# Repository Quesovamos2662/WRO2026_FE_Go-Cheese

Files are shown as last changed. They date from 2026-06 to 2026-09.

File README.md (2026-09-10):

<h1 align="center">🧀 Welcome to the Go!Cheese Repository 🧀</h1>

<div align="center">

━━━━━━━━━━━━━━━━━━━━━━━━━━━━━━━━━━━━

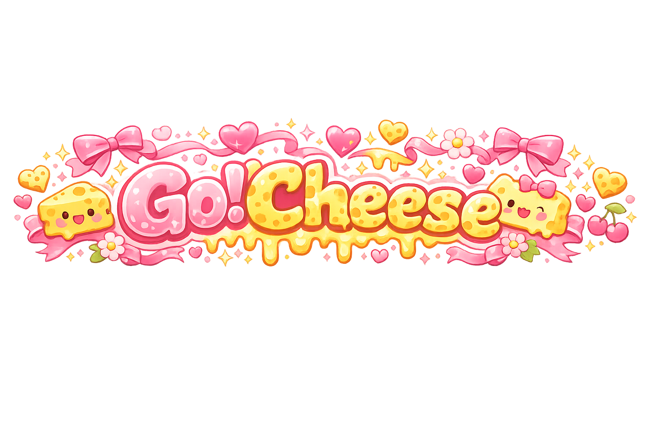
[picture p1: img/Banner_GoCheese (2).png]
Go!Cheese


━━━━━━━━━━━━━━━━━━━━━━━━━━━━━━━━━━━━

</div>

<h3 align="center"><em>"Cheese does run away from rats, right?"</em></h3>

<p align="center">
  
  
  
  
</p>

<p align="center">
  
  
  
  
  
</p>

---

Welcome to the official repository of **Go!Cheese**, a robotics team from San Miguelito, Panama, competing in the **WRO Future Engineers 2026** season.

This repository documents the complete engineering journey behind our autonomous vehicle, **Cheese**. It includes the development of the chassis, steering, drivetrain, electronics, sensors, vision system, software, testing process, failures, redesigns, and the decisions that eventually produced our current **Cheese v4**.

Our goal is not only to show the final robot.

We want the repository to explain:

> **What we built → why we built it that way → what failed → what we changed → what happened next.**

<div align="center">

| Project Information | Current Configuration |
| :--- | :--- |
| **Competition** | WRO Future Engineers 2026 |
| **Team** | Go!Cheese |
| **Region** | San Miguelito, Panama |
| **Current Robot** | Cheese v4 |
| **Controller** | LEGO Mindstorms EV3 |
| **Programming** | Python 3 (`ev3dev2`) + C++ Arduino bridge |
| **Vision** | HuskyLens |
| **Vision Interface** | Arduino Nano |
| **Propulsion** | EV3 Large Motor |
| **Steering** | EV3 Medium Motor + Ackermann geometry |
| **Distance Sensors** | 3 EV3 Ultrasonic Sensors |
| **Floor Detection** | EV3 Color Sensor |
| **Current Mass** | **666 g** |

</div>

---

<h3 align="center">Check us out! 👇</h3>

<p align="center">
  <a href="https://www.youtube.com/@GoCheese-pty" target="_blank">
    
  </a>
  <a href="https://github.com/Quesovamos2662" target="_blank">
    
  </a>
</p>

---

# WRO2026_FE_Go!Cheese

## 📌 Project Rundown

### Cheese Goal & Structure

Cheese is an autonomous LEGO Mindstorms EV3 vehicle designed for the **WRO Future Engineers 2026** competition.

The current robot is **Cheese v4**, the fourth major version of our platform.

Rather than using one fixed movement sequence, Cheese repeatedly reads its sensors and chooses a response based on the current situation.

Its main navigation systems include:

- PID wall-distance correction,
- progressive wall protection,
- color-based curve counting,
- front-distance safety,
- reverse recovery,
- obstacle recognition,
- camera-based steering influence,
- and final parking logic.

The software and mechanical architecture were designed together.

A good PID controller cannot compensate forever for a loose steering mechanism.

A correctly trained camera cannot help if the robot never places the obstacle inside its field of view.

A good color algorithm cannot work consistently if the sensor is mounted too far from the floor.

For this reason, our development philosophy became:

<p align="center">
  <strong>
    Mechanics + Sensors + Software + Testing = Reliable Behavior
  </strong>
</p>

---

### Open Challenge Logic

The Open Challenge is currently the most reliable part of Cheese v4.

The robot uses:

- left ultrasonic distance,
- right ultrasonic distance,
- front ultrasonic safety information,
- EV3 Color Sensor readings,
- PID steering,
- wall protection,
- curve validation,
- and parking logic.

A simplified Open control cycle is:

```text
START
  ↓
INITIALIZE
  ↓
READ ULTRASONIC SENSORS
  ↓
READ COLOR SENSOR
  ↓
CHECK FRONT SAFETY
  ↓
WALL PROTECTION?
  ↓
PID / STEERING CORRECTION
  ↓
VALID COLOR TRANSITION?
  ↓
UPDATE CURVE COUNT
  ↓
12 CURVES?
  ├── NO → CONTINUE
  └── YES → FINAL PARKING
```

A valid curve is based on a confirmed transition between the track colors:

```text
BLUE → ORANGE
```

or:

```text
ORANGE → BLUE
```

The current program expects:

```text
4 curves per lap × 3 laps = 12 curves
```

After the twelfth validated curve, Cheese enters its final parking procedure.

---

### Obstacle Challenge Logic

The Obstacle Challenge adds the **HuskyLens + Arduino Nano** vision subsystem.

The data path is:

```text
HuskyLens
    ↓
I2C
    ↓
Arduino Nano
    ↓
USB
    ↓
EV3
    ↓
Obstacle Navigation Logic
    ↓
Steering + Drive
```

The camera is currently trained for the competition obstacle colors:

| HuskyLens ID | Pillar | Required Passing Side |
| :---: | :---: | :--- |
| **ID 1** | 🔴 Red | Pass on the **right** |
| **ID 2** | 🟢 Green | Pass on the **left** |

The current obstacle challenge is functional but still being calibrated.

The main difficulty is no longer only recognizing the pillar.

It is completing the entire chain:

<p align="center">
  <strong>
    Detect → React → Avoid → Clear → Recover → Prepare for Next Obstacle
  </strong>
</p>

Post-obstacle recovery remains one of our main development priorities.

---

# General Project Index

This index connects the complete engineering documentation of Cheese.

Each section focuses on one part of the robot while remaining connected to the complete system.

---

## 🧀 General Project Overview

### [General Project Overview](sections/01-mobility-and-mechanical-design/project%20overview.md)

- Introduces Cheese and the WRO Future Engineers project.
- Explains the current Cheese v4 architecture.
- Summarizes the mechanical, electrical, software, sensing, testing, and development strategy.
- Introduces the progression from earlier versions to the current robot.

---

# 1. Mobility and Mechanical Design

## [1.1 Mechanical Design](sections/01-mobility-and-mechanical-design/1.1-mechanical-design.md)

- Explains the mechanical architecture behind Cheese.
- Documents propulsion and steering motor selection.
- Covers wheel decisions, drivetrain behavior, mechanical calculations, and testing.
- Connects mechanical changes to observed driving behavior.
- Documents changes introduced in Cheese v4.

## [1.2 Structural Components](sections/01-mobility-and-mechanical-design/1.2-structural-component.mds.md)

- Documents the LEGO Technic components used throughout the chassis.
- Explains liftarms, pins, axles, connectors, and critical supports.
- Separates critical structure from removable structure.
- Shows how v4 removed unnecessary components while keeping important mechanical supports.
- Includes structural evidence from the v3 → v4 redesign.

## [1.3 Steering and Drive](sections/01-mobility-and-mechanical-design/1.3-steering-and-drive.md)

- Explains the EV3 Large Motor rear-wheel-drive system.
- Explains the EV3 Medium Motor steering mechanism.
- Documents the Ackermann steering geometry.
- Shows how the steering linkage transfers motor rotation to the front wheels.
- Includes v1 → v2 → v3 → v4 steering development.
- Includes the dedicated v3 → v4 steering comparison.

## [1.4 Chassis Explanation](sections/01-mobility-and-mechanical-design/1.4-chassis-explanation.md)

- Explains how the chassis supports every major subsystem.
- Documents the lower EV3 position.
- Shows the motor, sensor, Nano, camera, and wiring placement.
- Explains the transition from the heavier v3 structure to the simplified v4 chassis.
- Documents the removal of unnecessary lighting and structural elements.

---

# 2. Power and Sensor Architecture

## [2.1 Power Supply and EV3](sections/02-power-and-sensor-architecture/2.1-power-supply-and-ev3.md)

- Documents the EV3 rechargeable battery.
- Explains the EV3 Brick as the central controller.
- Shows the lower physical EV3 placement in v4.
- Discusses battery consistency during testing.
- Explains why different battery conditions can affect physical motor response.
- Documents the use of two rechargeable EV3 batteries during repeated testing.

## [2.2 Wiring Diagram](sections/02-power-and-sensor-architecture/2.2-wiring-diagram.md)

- Documents the complete electrical architecture.
- Includes the system architecture diagram.
- Includes technical EV3 wiring.
- Explains sensor inputs and motor outputs.
- Documents the EV3 → Arduino Nano USB connection.
- Documents the Arduino Nano ↔ HuskyLens I2C connection.
- Includes real wiring photographs for reproducibility.

## [2.3 Sensor Selection and Placement](sections/02-power-and-sensor-architecture/2.3-sensor-selection-and-placement.md)

- Explains why Cheese uses three ultrasonic sensors.
- Documents left, right, and front ultrasonic placement.
- Explains the color sensor's floor-facing position.
- Documents the HuskyLens viewing position.
- Explains the compact front camera + ultrasonic arrangement.
- Connects physical sensor geometry to software reliability.

## [2.4 Sensor Calibration](sections/02-power-and-sensor-architecture/2.4-sensor-calibration.md)

- Documents color-sensor calibration.
- Explains the current EV3 color grouping.
- Covers ultrasonic filtering and distance thresholds.
- Documents PID calibration.
- Explains front-wall safety and reverse recovery.
- Documents HuskyLens obstacle IDs and camera reliability.
- Connects physical placement, sensor readings, and software interpretation.

---

# 3. Software and Obstacle Strategy

## [3.0 Cheese Logic Overview](sections/03-software-and-obstacle-strategy/3.0%20Cheese%20Logic%20Overview.md)

- Introduces the complete current software architecture.
- Explains the main sensor → decision → movement relationship.
- Separates Open Challenge logic from Obstacle Challenge logic.
- Introduces software priorities and safety behavior.

## [3.1 Algorithm Architecture](sections/03-software-and-obstacle-strategy/3.1-algorithm-architecture.md)

- Explains the internal software structure.
- Documents PID centering.
- Explains wall protection.
- Covers front-distance recovery.
- Documents color-based curve counting.
- Explains obstacle camera influence.
- Shows how competing behaviors are prioritized.

## [3.2 Flowchart](sections/03-software-and-obstacle-strategy/3.2-flowchart.md)

- Contains the current v4 software flowcharts.
- Shows the main software control cycle.
- Documents curve detection.
- Documents PID behavior.
- Shows front-wall reverse recovery.
- Shows obstacle camera behavior.
- Documents parking and sensor validation logic.

## [3.3 Open Challenge](sections/03-software-and-obstacle-strategy/3.3-open-challenge.md)

- Documents the current Open Challenge strategy.
- Explains wall following.
- Covers PID control and wall protection.
- Documents the front ultrasonic safety system.
- Explains curve counting.
- Covers the 12-curve / three-lap logic.
- Documents the current parking strategy.

## [3.4 Obstacle Challenge](sections/03-software-and-obstacle-strategy/3.4-obstacle-challenge.md)

- Explains red and green obstacle recognition.
- Documents HuskyLens communication through the Nano.
- Explains camera steering influence.
- Covers PID + camera interaction.
- Documents obstacle avoidance.
- Explains the current post-obstacle recovery problem.
- Records remaining testing priorities.

## [3.5 Corner Handling](sections/03-software-and-obstacle-strategy/3.5-corner-handling.md)

- Explains how Cheese enters and exits corners.
- Documents the BLUE ↔ ORANGE color sequence.
- Explains steering confirmation.
- Documents curve cooldown.
- Connects curve count directly to parking.
- Explains current corner failures and improvements.

## [3.6 Tuning Process](sections/03-software-and-obstacle-strategy/3.6-tuning-process.md)

- Documents the real tuning order used by the team.
- Covers mechanical tuning.
- Documents color calibration.
- Explains PID tuning.
- Covers curve tuning.
- Documents parking adjustments.
- Explains obstacle tuning.
- Records current Open and Obstacle status.

---

# 4. Engineering Decisions

## [4.1 Design Decision Log](sections/04-engineering-decisions/4.1-design-decision-log.md)

- Records major engineering decisions throughout development.
- Explains why components were added, moved, changed, or removed.
- Documents the transition from v3 to v4.
- Connects observed problems to engineering responses.
- Discusses trade-offs between mass, support, complexity, sensing, and reliability.

## [4.2 What Did Not Work](sections/04-engineering-decisions/4.2-what-didnt-work.md)

- Documents failures instead of hiding them.
- Explains mechanical failures.
- Covers sensor problems.
- Documents steering issues.
- Covers curve and parking failures.
- Explains unsuccessful lighting or structural strategies.
- Connects each failure to the next engineering decision.

---

# 5. Reproducibility

## [5.1 Bill of Materials](sections/05-reproducibility/5.1-bill-of-materials.md)

- Documents the components used in Cheese v4.
- Includes the EV3 Brick and rechargeable battery.
- Includes Large and Medium Motors.
- Includes the three ultrasonic sensors.
- Includes the EV3 Color Sensor.
- Includes the HuskyLens.
- Includes the Arduino Nano.
- Documents the LEGO Technic structural components.
- Separates critical and flexible components.

## [5.2 Build Instructions](sections/05-reproducibility/5.2-build-instructions.md)

- Provides a reproducible construction sequence.
- Documents chassis building.
- Explains motor installation.
- Covers Ackermann steering construction.
- Documents sensor mounting.
- Covers EV3 and Nano placement.
- References electrical wiring.
- Includes calibration and initial testing guidance.

---

# 6. Additional Resources

## [6.1 Additional Resources](sections/06-other-resources/6.1-additional-resources.md)

- Contains supporting engineering resources.
- Includes current v4 graphs.
- Includes historical v3 evidence where useful.
- Documents the transition between versions.
- Contains testing visualizations.
- Includes tuning and performance references.
- Supports deeper analysis beyond the main documentation.

---

# 7. Source Code

## [Source Code Folder](src/)

The `src/` folder contains the program files used during development.

The code history documents:

- Open Challenge development,
- Obstacle Challenge development,
- PID iterations,
- wall correction,
- curve counting,
- front recovery,
- camera integration,
- steering tests,
- parking logic,
- and experimental code versions.

Because software changed repeatedly during testing, older files are also useful engineering evidence.

They show how the current control system evolved rather than presenting the final program as if it appeared in one attempt.

---

# 8. Digital Models and Schemes

## [Robot Models](models/)

The models directory contains digital references related to Cheese's structure and development.

These resources complement physical photographs by helping document the robot's geometry and assembly.

## [Technical Schemes](schemes/)

The `schemes/` directory contains technical diagrams and reference documents.

Current resources include:

- complete system architecture,
- technical wiring,
- Nano ↔ HuskyLens wiring,
- final robot construction reference,
- steering comparison,
- and legacy wiring references.

<p align="center">
  <a href="schemes/Cheese_V4_Complete_System_Architecture_Wiring_Diagram.pdf">
    
  </a>
</p>

<p align="center">
  <a href="schemes/cheese_v4_technical_wiring_diagram.pdf">
    
  </a>
</p>

<p align="center">
  <a href="schemes/arduino_nano_huskylens_wiring_v4.pdf">
    
  </a>
</p>

<p align="center">
  <a href="schemes/steering_comparison_v3_to_v4.pdf">
    
  </a>
</p>

---

# 9. Visual Documentation

Our photo folders preserve the development of Cheese across the season.

## [Version 1 Photos](v-photos/v1/)

Documents the earliest physical ideas and provides historical evidence of the first steering and chassis concepts.

## [Version 2 Photos](v-photos/v2/)

Documents the first major physical competition version and important steering redesigns.

## [Version 3 Photos](v-photos/v3/)

Documents the heavier reinforced robot that preceded the current design.

Version 3 remains important because many v4 decisions were direct responses to problems identified in v3.

## [Version 4 Photos](v-photos/v4/)

Documents the **current Cheese v4** configuration.

The folder includes:

- front,
- back,
- left,
- right,
- top,
- bottom,
- chassis,
- motors,
- steering,
- ultrasonic sensors,
- color sensor,
- HuskyLens,
- Arduino Nano,
- battery,
- wiring,
- removed structural pieces,
- and removed lighting components.

---

# 10. Team Documentation

## [Team Photos](t-photos/)

The team documentation shows the people behind the vehicle and complements the technical engineering evidence.

---

<p align="center">
  <strong>
    This index connects every major part of the repository so the engineering process
    can be followed from concept → prototype → failure → redesign → testing → current v4.
  </strong>
</p>

---

<h2 align="center">🧀 Team Goals: Road to the National Finals 🧀</h2>

<p align="center">
  <em>
    Building Cheese is not only about competing. It is about learning how to think,
    test, fail, document, and improve like engineers.
  </em>
</p>

<div align="center">

| Goal | What We Want to Achieve |
| :--- | :--- |
| **🧊 Freeze Stable Code** | Once Open and Obstacle behavior reaches acceptable reliability, we want to avoid major last-minute changes and focus on repetition, calibration, and verification. |
| **🏁 Make Open Repeatable** | The current Open system can complete three laps and park. Our next objective is increasing repeatability across different starts and battery conditions. |
| **🚧 Complete Obstacle Reliability** | The HuskyLens can identify the pillars and affect movement, but avoidance and especially recovery still require calibration. |
| **📚 Make Documentation Count** | Every important decision should include the failure, cause, correction, result, and engineering lesson whenever evidence is available. |
| **🔧 Improve Reproducibility** | Another team should be able to understand Cheese's mechanics, sensors, wiring, software, and testing process from this repository. |
| **🏁 Earn Our Place at Nationals** | We want our performance and documentation to demonstrate how much Cheese improved throughout the season. |
| **🌱 Build a Reference for Future Us** | This is our first season in Future Engineers, so we want to leave behind a strong engineering foundation that can be improved later. |

</div>

<p align="center">
  <strong>Our main objective is to make Cheese more than a robot:</strong><br>
  a documented engineering project built through testing, iteration, teamwork, and constant improvement.
</p>

---

<h1 align="center">ᯓ★ Meet the Big Cheese! ᯓ★</h1>

<p align="center">
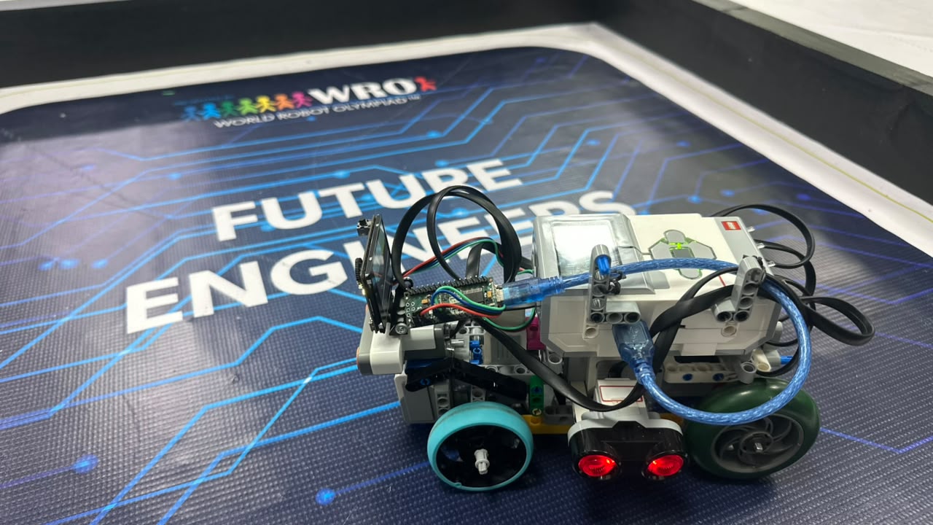
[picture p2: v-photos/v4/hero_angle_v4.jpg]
Cheese v4 current robot
  
</p>

<p align="center">
  <em>Cheese v4 — current Go!Cheese WRO Future Engineers vehicle.</em>
</p>

Cheese v4 represents a major change in our design philosophy.

Version 3 focused heavily on reinforcement.

That solved several mechanical problems, but it also produced a robot with:

- more upper structure,
- more pins and liftarms,
- a larger camera support,
- longer cable routing,
- auxiliary lighting hardware,
- and a total mass of approximately **888.8 g**.

During the transition to v4, we asked a different question:

> **Which parts are actually necessary for the robot to work reliably?**

Instead of adding more structure, we began removing components that did not provide enough mechanical or sensing benefit.

The result was a **666 g** robot.

That represents a reduction of approximately:

```text
888.8 g − 666 g = 222.8 g
```

or about **223 g**.

---

## ❀ Current v4 Technical Overview ────୨ৎ────────୨ৎ────

| Core Subsystem | Current Cheese v4 Implementation |
| :--- | :--- |
| **Main Controller** | LEGO Mindstorms EV3 Brick |
| **Software** | Python 3 using `ev3dev2` |
| **External Interface** | Arduino Nano |
| **Vision Sensor** | HuskyLens |
| **Drive Motor** | EV3 Large Motor |
| **Steering Motor** | EV3 Medium Motor |
| **Drive Layout** | Rear-wheel drive |
| **Steering Geometry** | Front Ackermann steering |
| **Front Wheels** | LEGO SPIKE wheel assemblies |
| **Distance Sensors** | 3 EV3 Ultrasonic Sensors |
| **Floor Sensor** | EV3 Color Sensor |
| **Main Battery** | EV3 Rechargeable Battery |
| **Auxiliary Lighting** | Removed from current v4 configuration |
| **Current Mass** | **666 g** |

The current robot's dimensions are intentionally not listed here until a new complete v4 measurement set is verified.

---

## ❀ Cheese v4 Physical Layout ────୨ৎ────────୨ৎ────

<p align="center">
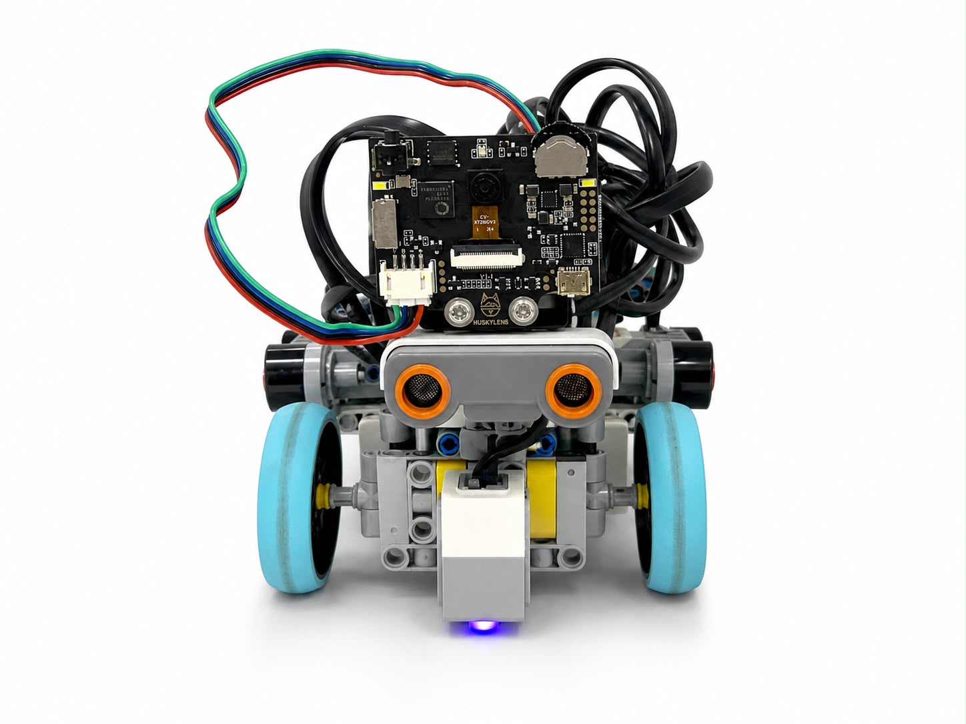
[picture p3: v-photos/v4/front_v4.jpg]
Cheese v4 front view
  
  &nbsp;
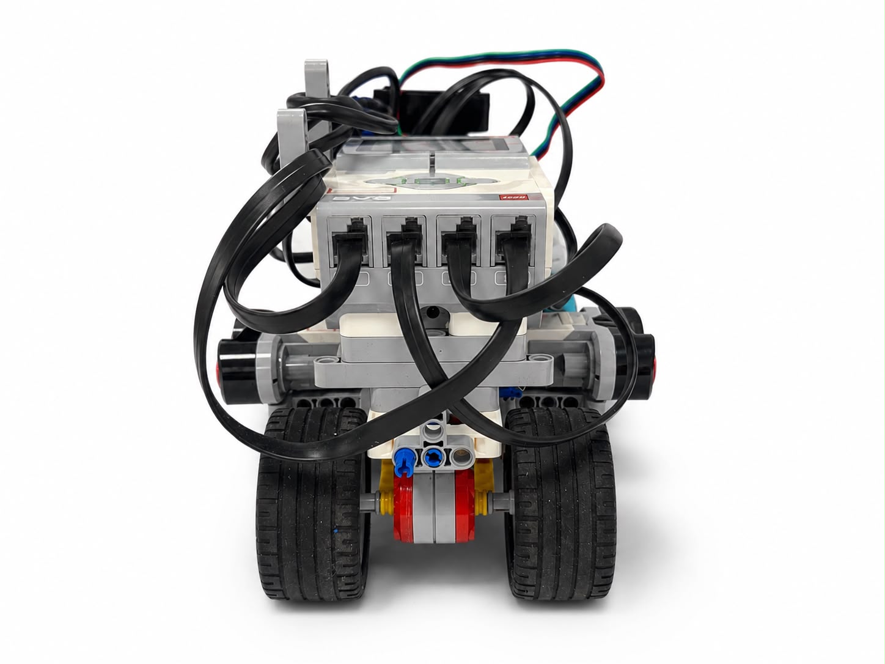
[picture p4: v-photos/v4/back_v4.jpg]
Cheese v4 back view
  
</p>

<p align="center">
  <em>Front and rear views of the current Cheese v4 configuration.</em>
</p>

<p align="center">
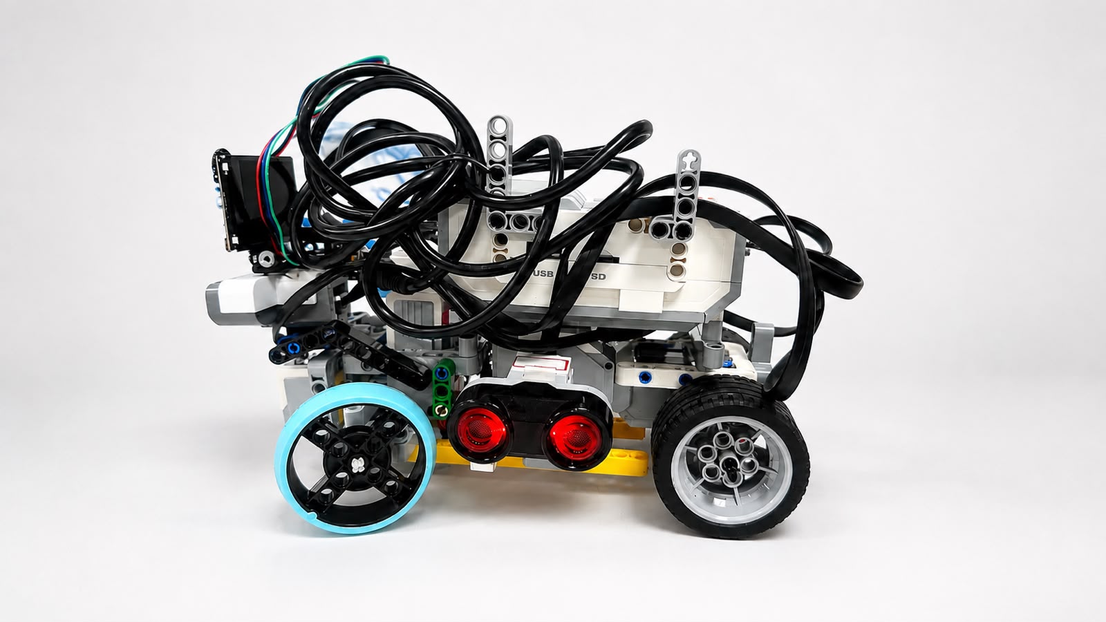
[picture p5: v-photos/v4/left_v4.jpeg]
Cheese v4 left side
  
  &nbsp;
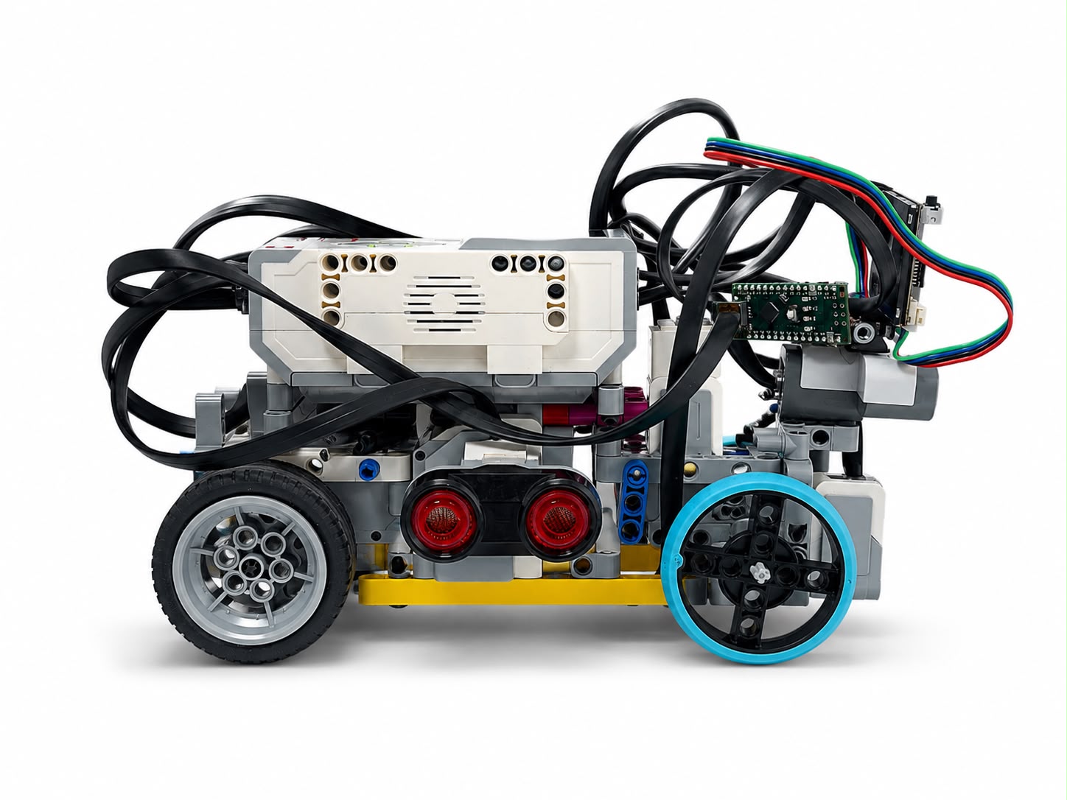
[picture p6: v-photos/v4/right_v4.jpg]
Cheese v4 right side
  
</p>

<p align="center">
  <em>Side views showing the lower and more compact v4 structure.</em>
</p>

<p align="center">
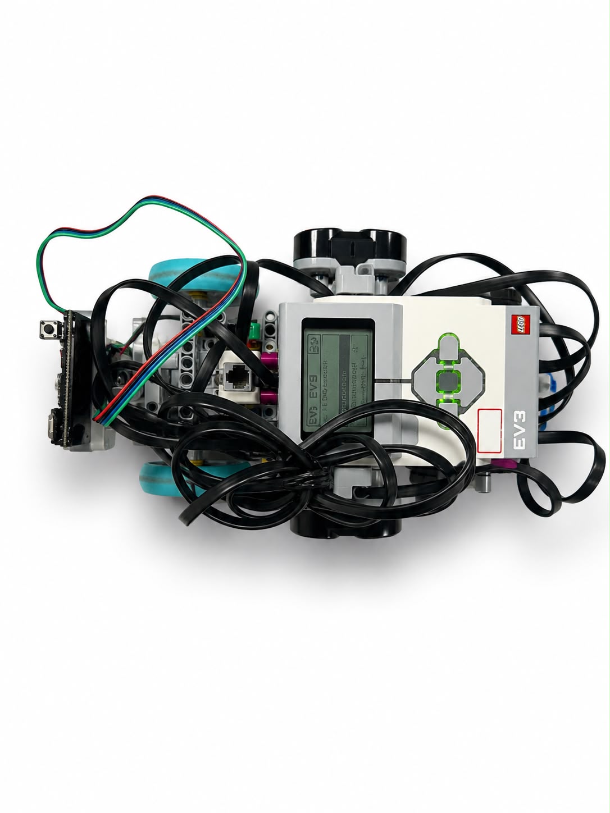
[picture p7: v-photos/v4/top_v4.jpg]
Cheese v4 top view
  
  &nbsp;
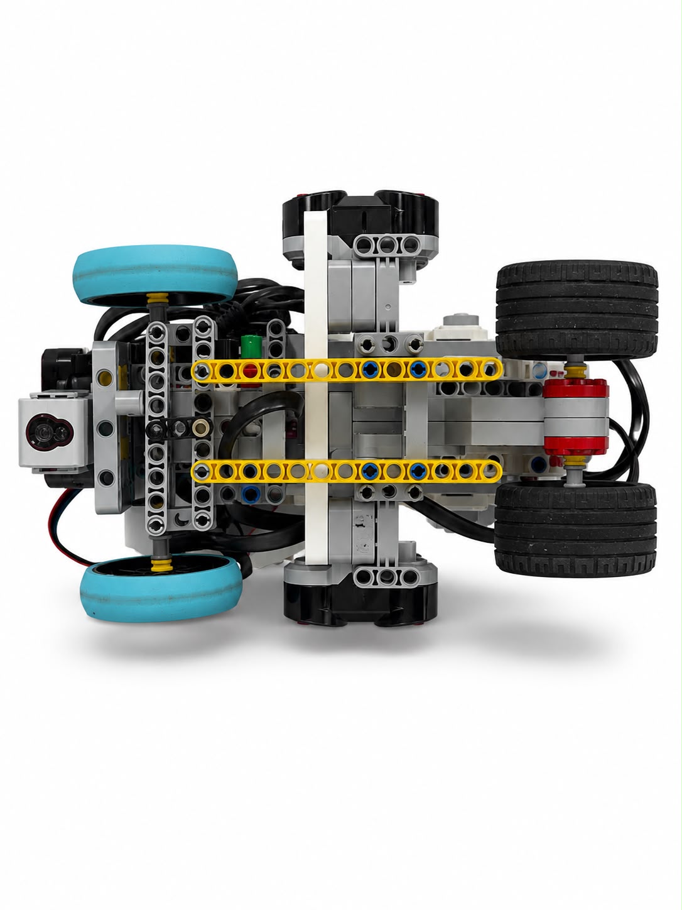
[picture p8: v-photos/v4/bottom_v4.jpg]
Cheese v4 bottom view
  
</p>

<p align="center">
  <em>Top and bottom views documenting the current mechanical arrangement.</em>
</p>

---

## ❀ Major v4 Mechanical Changes ────୨ৎ────────୨ৎ────

### Lower EV3 Brick

The EV3 Brick is positioned lower and flatter than in the previous configuration.

This helped remove unnecessary upper structure while keeping the controller accessible.

### Horizontal Large Motor

The drive motor is integrated horizontally into the chassis.

This helps use the available internal space more efficiently.

### SPIKE Front Wheels

The current front wheel assemblies use LEGO SPIKE-style wheels.

The change was made during the redesign of the front steering system and current testing has shown improved front-end response and grip.

### Reduced Upper Structure

The large previous camera/support tower was simplified.

Only structure with a useful mechanical role was retained.

### Removed Auxiliary Lighting

The auxiliary lighting system used during previous testing is not part of normal v4 operation.

Removing it reduced:

- wiring,
- mounting hardware,
- upper structure,
- and electrical complexity.

---

# 🏁 Achievements & Track Milestones

This section summarizes some of the main milestones that shaped the current robot.

Each milestone represents either a performance improvement, a design decision, or a development lesson.

<table>
  <tr>
    <td width="28%" align="center"><strong>Regional Experience</strong></td>
    <td>
      Competition experience showed us that performance alone was not enough.
      We also needed stronger software documentation, better evidence, and a clearer
      explanation of why each system existed.
    </td>
  </tr>

  <tr>
    <td width="28%" align="center"><strong>v3 Reinforcement</strong></td>
    <td>
      Cheese v3 became mechanically stronger, but its mass increased to approximately
      888.8 g. This taught us that reinforcement solves mechanical problems while
      potentially creating mass, complexity, and accessibility problems.
    </td>
  </tr>

  <tr>
    <td width="28%" align="center"><strong>666 g v4</strong></td>
    <td>
      Cheese v4 reduced mass by approximately 223 g while preserving the
      drivetrain, steering, sensor support, EV3, HuskyLens, Arduino Nano, and
      competition functionality.
    </td>
  </tr>

  <tr>
    <td width="28%" align="center"><strong>Three-Lap Open</strong></td>
    <td>
      The current Open Challenge system can complete the three-lap sequence
      using PID control, ultrasonic wall information, color-based curve counting,
      front safety, and final parking logic.
    </td>
  </tr>

  <tr>
    <td width="28%" align="center"><strong>Open Lap Speed</strong></td>
    <td>
      Current testing generally produces approximately 30–35 second laps,
      with a complete three-lap run around 80–90 seconds depending on conditions.
    </td>
  </tr>

  <tr>
    <td width="28%" align="center"><strong>Parking</strong></td>
    <td>
      Cheese can stop inside the parking area after completing the Open sequence.
      Final alignment can still vary and remains part of tuning.
    </td>
  </tr>

  <tr>
    <td width="28%" align="center"><strong>Obstacle Recognition</strong></td>
    <td>
      The HuskyLens is trained to identify the competition red and green pillars.
      The camera information already influences the obstacle navigation system.
    </td>
  </tr>

  <tr>
    <td width="28%" align="center"><strong>Current Obstacle Challenge</strong></td>
    <td>
      The main obstacle-development challenge is now obtaining reliable avoidance
      and recovery so Cheese is correctly positioned for the next pillar.
    </td>
  </tr>
</table>

---

# 🔄 Structural Evolution — v1 → v2 → v3 → v4

Cheese did not reach its current form in one build.

Each version was shaped by what the previous one taught us.

Our redesigns were responses to real problems:

- steering stiffness,
- chassis instability,
- sensing limitations,
- camera integration,
- structural stress,
- excessive mass,
- cable complexity,
- and navigation reliability.

<div align="center">

| Aspect | v1 | v2 | v3 | v4 |
| :--- | :--- | :--- | :--- | :--- |
| **Stage** | Early concept / digital development | First major physical competition build | Reinforced vision build | Current competition build |
| **EV3 Position** | Early vertical concept | Horizontal | Horizontal / higher structure | **Lower and flatter** |
| **Steering** | Initial stiff linkage | Redesigned linkage | Reinforced steering support | **Simplified supported Ackermann system** |
| **Distance Sensors** | Early mixed configuration | 3 ultrasonics | Reduced/changed configuration during development | **3 ultrasonic sensors** |
| **Color Sensor** | Not central | Development stage | Added for track events | **Current curve-count sensor, slightly lower** |
| **Camera** | None | None | HuskyLens introduced | **Lower HuskyLens position** |
| **Arduino Nano** | None | None / development | Vision bridge | **Current vision bridge** |
| **Lighting** | None | Development | Auxiliary lighting added | **Removed** |
| **Structure** | Compact concept | First stable structure | Heavy reinforcement | **Simplified structure** |
| **Mass** | Not representative | ~763.5 g | ~888.8 g | **666 g** |

</div>

---

## ❀ What v1 Taught Us

The first design helped us understand the basic physical arrangement of the robot.

However, some ideas that looked reasonable digitally did not behave the same way once LEGO friction, steering resistance, motor placement, and real track movement were considered.

The early steering system became one of the first areas requiring redesign.

---

## ❀ What v2 Taught Us

Version 2 became an important physical development stage.

It helped establish a more functional steering geometry and provided our first meaningful competition and track experience.

The robot was physically lighter than v3, but several systems still needed redesign for improved reliability.

---

## ❀ What v3 Taught Us

Version 3 prioritized structural reinforcement.

The robot gained:

- stronger steering support,
- a HuskyLens camera,
- Arduino integration,
- a larger upper structure,
- additional wiring,
- and auxiliary lighting.

These changes solved important problems.

However, they also pushed the robot to approximately **888.8 g**.

The lesson was not that v3 was a bad design.

It was that:

> **A solution to one problem can become the source of the next engineering problem.**

The stronger structure improved rigidity.

But the additional mass and complexity became the next design challenge.

---

## ❀ Why v4 Exists

Version 4 was designed to preserve the useful lessons from v3 while removing unnecessary complexity.

The main v4 question became:

> **What can we remove without reducing reliability?**

The redesign removed:

- large upper camera support elements,
- unnecessary liftarms,
- extra pins and axles,
- previous lighting hardware,
- lighting supports,
- excess upper structure,
- and longer cable routing.

At the same time, v4 retained:

- the EV3 controller,
- Ackermann steering,
- Large Motor propulsion,
- Medium Motor steering,
- three ultrasonics,
- color sensing,
- HuskyLens vision,
- Arduino Nano communication,
- battery access,
- and critical steering supports.

---

## ❀ Physical Evidence of Simplification ────୨ৎ────────୨ৎ────

<p align="center">
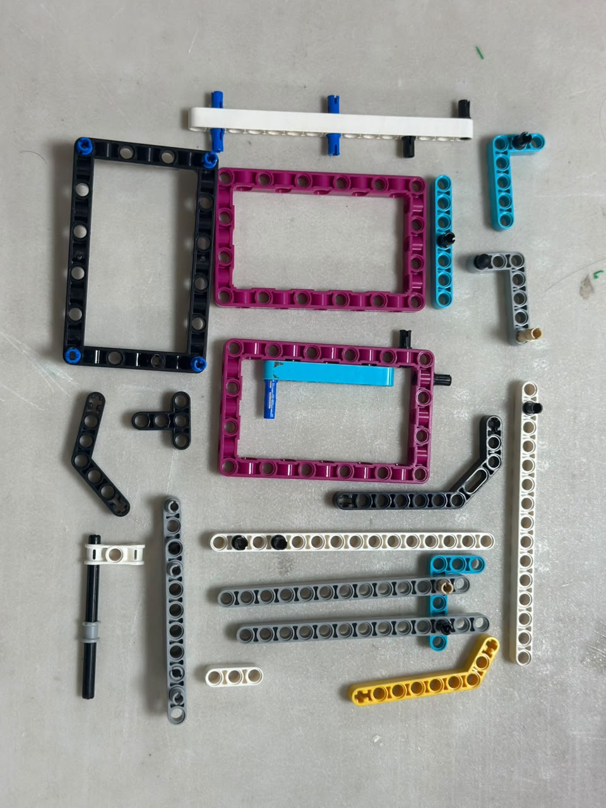
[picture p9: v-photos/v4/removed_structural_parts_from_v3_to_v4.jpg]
Structural components removed from Cheese v3 to v4
  
</p>

<p align="center">
  <em>Structural components removed during the transition from Cheese v3 to Cheese v4.</em>
</p>

<p align="center">
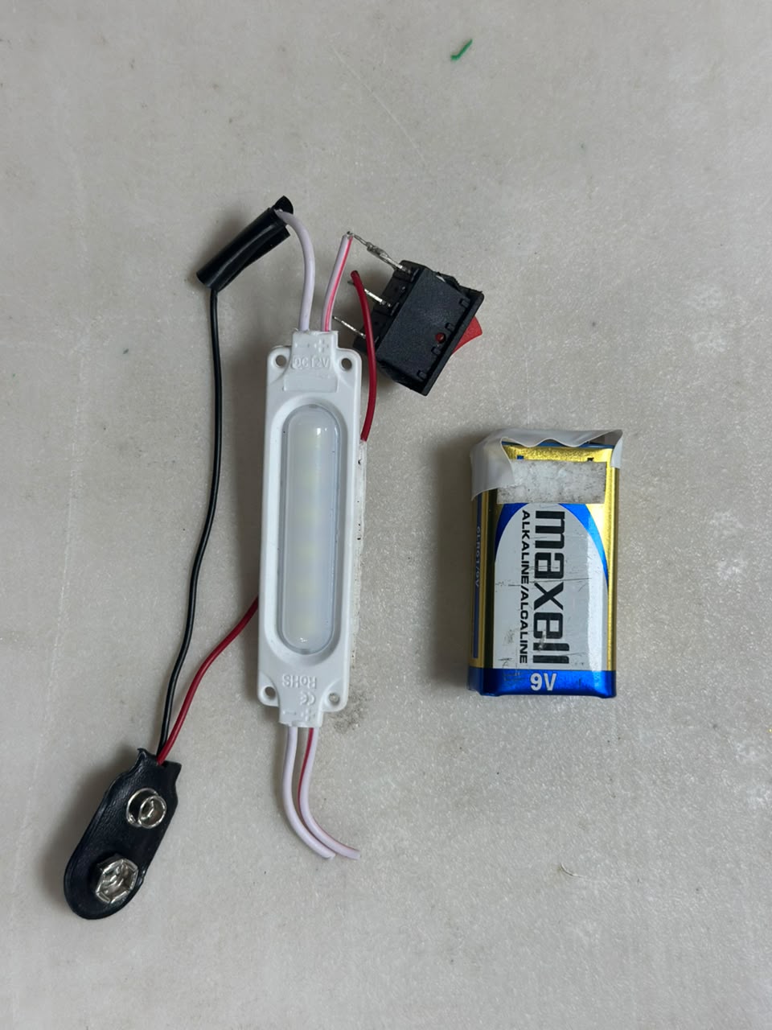
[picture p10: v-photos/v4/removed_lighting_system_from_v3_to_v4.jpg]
Lighting components removed during Cheese v4 redesign
  
</p>

<p align="center">
  <em>Previous auxiliary lighting hardware removed from the normal v4 architecture.</em>
</p>

The v3 → v4 transition therefore followed:

```text
HEAVY BUT STABLE v3
        ↓
IDENTIFY NON-CRITICAL MASS
        ↓
REMOVE / REPOSITION COMPONENTS
        ↓
RETEST STRUCTURE
        ↓
KEEP CRITICAL SUPPORTS
        ↓
666 g v4
```

---

# 🛞 Steering Evolution

Steering has been one of the most important mechanical systems throughout Cheese's development.

The EV3 Medium Motor controls the front linkage.

The front wheels use Ackermann-style geometry so the inner and outer wheels can follow different paths through a turn.

The current v4 system retains the steering principles developed during earlier versions while simplifying the surrounding structure.

<p align="center">
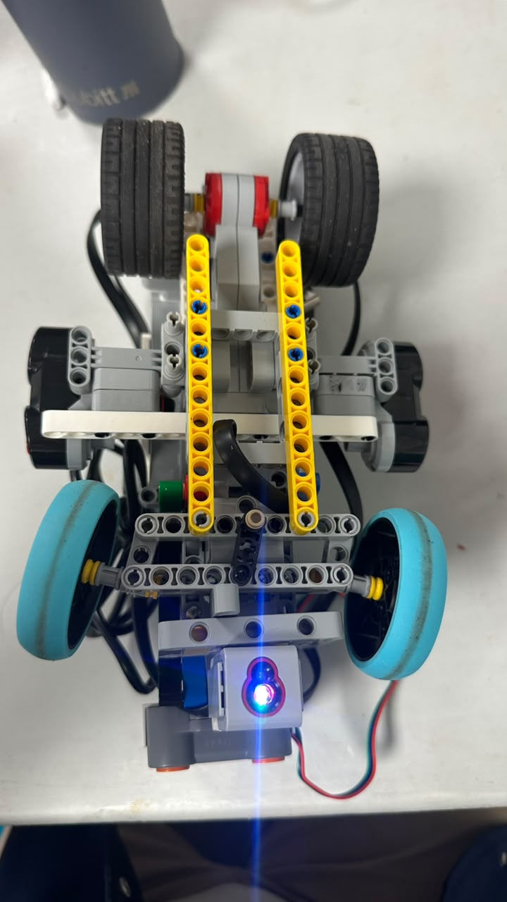
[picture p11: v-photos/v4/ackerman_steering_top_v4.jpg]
Cheese v4 Ackermann steering
  
</p>

<p align="center">
  <em>Top view of the current Cheese v4 steering system.</em>
</p>

<p align="center">
  <a href="schemes/steering_comparison_v3_to_v4.pdf">
    
  </a>
</p>

The main steering lesson became:

> **A linkage must be free enough to move, but supported enough to remain aligned.**

---

# 🧠 Cheese's Logic

Cheese uses a **priority-based navigation architecture**.

This means multiple systems can request steering or movement changes, but the software determines which response is most important at a given moment.

The main priorities include:

1. dangerous wall / front-distance protection,
2. obstacle reaction when relevant,
3. curve behavior,
4. normal PID wall control,
5. parking / finish behavior when the run is complete.

The exact priority can vary between Open and Obstacle code.

---

## ❀ Main Software Cycle ────୨ৎ────────୨ৎ────

```text
INITIALIZE
    ↓
READ SENSORS
    ↓
VALIDATE READINGS
    ↓
FRONT DANGER?
    ├── YES → SAFETY / REVERSE
    ↓ NO
WALL DANGER?
    ├── YES → WALL PROTECTION
    ↓ NO
OBSTACLE ACTIVE?
    ├── YES → CAMERA-BASED RESPONSE
    ↓ NO
NORMAL PID
    ↓
COLOR / CURVE LOGIC
    ↓
UPDATE COUNTERS
    ↓
PARKING READY?
    ├── YES → FINAL PARKING
    └── NO → NEXT LOOP
```

---

## ❀ Open Control Philosophy ────୨ৎ────────୨ৎ────

During Open navigation, Cheese continuously reads the ultrasonic sensors and uses the information to determine correction.

The PID controller is currently based around:

| Constant | Current Value |
| :--- | :---: |
| **KP** | 0.28 |
| **KI** | 0.001 |
| **KD** | 0.08 |
| **PID maximum steering angle** | 32° |
| **Center deadband** | 1.5 |

Wall protection becomes progressively stronger as the robot approaches the wall.

Current reference values include:

| Protection Parameter | Value |
| :--- | :---: |
| Gentle wall distance | 28 cm |
| Severe wall distance | 22 cm |
| Full avoidance distance | 15 cm |
| Gentle wall angle | 14° |
| Severe wall angle | 18° |

These values allow normal PID behavior to handle ordinary drift while stronger safety logic handles dangerous proximity.

---

## ❀ Front Safety ────୨ৎ────────୨ৎ────

The front ultrasonic sensor provides another navigation layer.

Current Open behavior includes:

- front assistance,
- too-close detection,
- confirmation,
- reverse recovery,
- and recovery distance.

When Cheese becomes too close to the front wall, reversing creates physical space for steering to become effective again.

```text
FRONT TOO CLOSE
      ↓
CONFIRM
      ↓
REVERSE
      ↓
CREATE SPACE
      ↓
RETURN TO NAVIGATION
```

---

## ❀ Curve Counting ────୨ৎ────────୨ৎ────

Cheese uses the floor color sensor to determine progress.

The sensor runs in `COL-COLOR` mode.

The current software interprets:

```text
BLUE = BLUE

RED
YELLOW  → ORANGE
BROWN
```

A valid transition:

```text
BLUE → ORANGE
```

or:

```text
ORANGE → BLUE
```

is used as part of curve validation.

Additional conditions include:

- steering confirmation,
- timing,
- and cooldown.

This is important because:

> **Seeing a color is not necessarily the same as physically completing a curve.**

---

# 🏁 Current Open Performance

The Open Challenge currently performs three laps with much greater reliability than earlier versions.

Current observations:

<div align="center">

| Open Capability | Current Status |
| :--- | :--- |
| Straight driving | ✅ Functional |
| PID correction | ✅ Functional |
| Wall protection | ✅ Functional |
| Front safety | ✅ Functional |
| Color detection | ✅ Functional |
| Curve counting | ✅ Functional |
| 3 complete laps | ✅ Mostly reliable |
| Parking area detection | ✅ Functional |
| Final alignment | 🟡 Still tuning |
| Battery sensitivity | 🟡 Still monitored |

</div>

Typical current timing is approximately:

```text
1 lap ≈ 30–35 seconds
3 laps ≈ 80–90 seconds
```

The exact time changes depending on battery condition, corrections, curve behavior, and parking.

---

# 🚧 Current Obstacle Performance

The Obstacle Challenge uses a different control emphasis.

The HuskyLens already recognizes red and green pillars.

The camera influences movement through the EV3 obstacle controller.

However, several real-world problems remain:

- a pillar may enter the camera's FOV too late,
- a poor curve exit can point the camera away from the next pillar,
- avoidance can sometimes be too weak,
- the robot can contact or carry an obstacle,
- and recovery after passing an obstacle can leave Cheese badly aligned.

The current largest obstacle priority is:

<p align="center">
  <strong>POST-OBSTACLE RECOVERY</strong>
</p>

because a successful first avoidance is not enough if the next pillar becomes impossible to detect.

---

# 🗺️ Current Software Flowcharts

The repository now includes a dedicated v4 flowchart set.

### [Open the complete Flowchart Section](sections/03-software-and-obstacle-strategy/3.2-flowchart.md)

Current diagrams include:

```text
00 — v4 Flowchart Set Map
01 — Main Loop Control Cycle
02 — Color Detection & Curve Counting
03 — Minimum Correction PID Controller
04 — Front Wall Safety / Reverse Recovery
05 — Obstacle Detection & Camera Bias
06 — Parking & Finish Logic
07 — Sensor Validation & Reliability
08 — Main Software Flowchart
```

<p align="center">
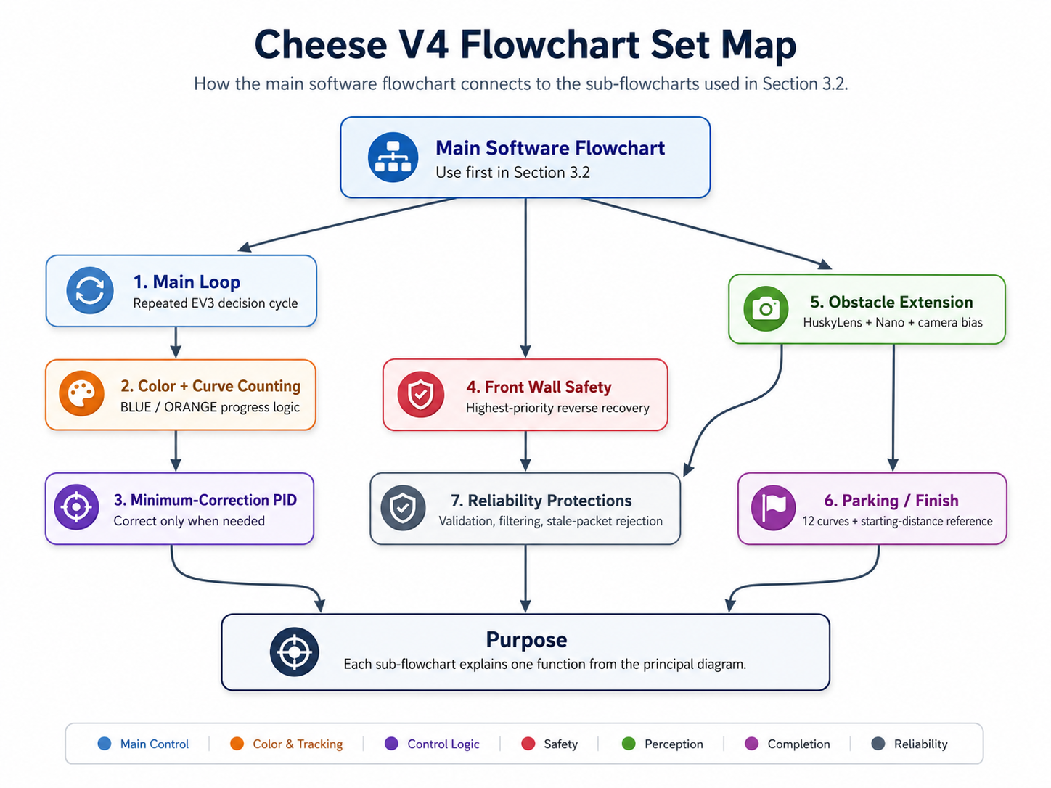
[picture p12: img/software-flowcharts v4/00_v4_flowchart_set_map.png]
Cheese v4 flowchart set map
  
</p>

<p align="center">
  <em>Current Cheese v4 software flowchart set.</em>
</p>

<p align="center">
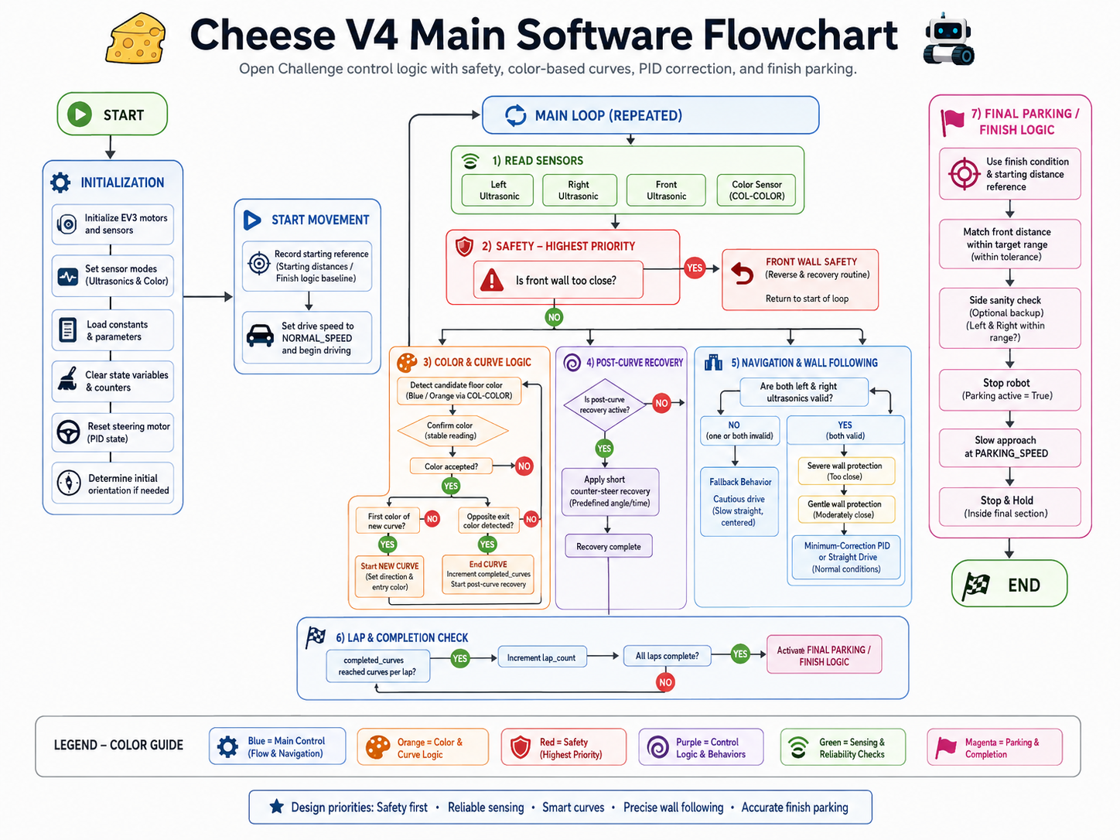
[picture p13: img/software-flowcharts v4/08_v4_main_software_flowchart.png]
Cheese v4 main software flowchart
  
</p>

<p align="center">
  <em>Main v4 software architecture.</em>
</p>

---

# 🔌 Current Electronic Architecture

Cheese combines the LEGO EV3 ecosystem with an external vision interface.

```text
                 EV3 BATTERY
                      ↓
                  EV3 BRICK
             ┌────────┼────────┐
             ↓        ↓        ↓
          MOTORS   SENSORS    USB
                               ↓
                         ARDUINO NANO
                               ↓
                              I2C
                               ↓
                           HUSKYLENS
```

The EV3 remains the main controller.

The Arduino Nano does not replace the EV3.

Its role is to bridge the external camera subsystem.

---

## ❀ Technical Wiring Resources ────୨ৎ────────୨ৎ────

<p align="center">
  <a href="schemes/Cheese_V4_Complete_System_Architecture_Wiring_Diagram.pdf">
    
  </a>
</p>

<p align="center">
  <a href="schemes/cheese_v4_technical_wiring_diagram.pdf">
    
  </a>
</p>

<p align="center">
  <a href="schemes/arduino_nano_huskylens_wiring_v4.pdf">
    
  </a>
</p>

---

# 📡 Sensor Architecture

The current robot uses three sensing layers.

## Distance Layer

```text
LEFT ULTRASONIC
RIGHT ULTRASONIC
FRONT ULTRASONIC
```

These provide wall and forward-distance information.

## Floor Layer

```text
EV3 COLOR SENSOR
```

This detects the track markers used by curve counting.

## Vision Layer

```text
HUSKYLENS
```

This provides obstacle identification.

Each sensor has one main responsibility.

This makes the system easier to debug and prevents one sensor type from being responsible for every navigation problem.

---

# 🔍 Current Front Sensor Architecture

The HuskyLens and front ultrasonic sensor share the front region of the robot.

They perform different jobs:

| Sensor | Question It Answers |
| :--- | :--- |
| **HuskyLens** | What colored obstacle is ahead? |
| **Front Ultrasonic** | How close is the object or wall ahead? |

This combination gives Cheese both **identity** and **distance** information.

---

# 🎨 Color Sensor Development

One of the more interesting sensor lessons came from environmental lighting.

Earlier testing showed that ambient light could affect floor detection.

A temporary physical cover was tested around the color sensor.

However, it created its own mechanical problems because it could contact the field.

The final v4 solution was simpler:

> **Move the color sensor slightly lower.**

This improved the sensor-to-floor geometry enough that the temporary light-blocking structure was no longer needed during normal operation.

This became a useful engineering example:

```text
SENSOR PROBLEM
    ↓
TRY SOFTWARE / PHYSICAL FIX
    ↓
NEW PROBLEM CREATED
    ↓
RETHINK GEOMETRY
    ↓
SIMPLER SOLUTION
```

---

# ⚙️ Engineering Development Method

We try not to treat a failed run as simply a bad run.

Instead, we use the following process:

```text
FAILURE
   ↓
OBSERVATION
   ↓
POSSIBLE CAUSE
   ↓
CHANGE
   ↓
TEST
   ↓
RESULT
   ↓
LESSON
```

For example:

| Failure | Possible Cause | Change | Result / Lesson |
| :--- | :--- | :--- | :--- |
| Wide curves | Steering/timing too weak | Adjust curve response | Tighter path |
| Zig-zag | Corrections too aggressive | Tune PID / steering | Smoother movement |
| Missed floor marker | Sensor conditions | Lower sensor / grouping | Better detection |
| Front wall crash | No space for steering | Reverse recovery | Creates steering space |
| Obstacle contact | Late/weak reaction | Camera/avoidance tuning | Still under calibration |
| Poor next obstacle detection | Bad recovery position | Recovery tuning | Current major focus |

---

# 🧀 Cheese v4 Visual Tour

Instead of showing only one image, this section provides a physical map of the current robot.

---

## ❀ Front View ────୨ৎ────────୨ৎ────

<p align="center">
  Cheese v4 front view
</p>

The front region contains the steering system and the main forward sensing area.

---

## ❀ Left View ────୨ৎ────────୨ৎ────

<p align="center">
  Cheese v4 left view
</p>

The side profile shows how much lower v4 became compared with the larger v3 upper structure.

---

## ❀ Right View ────୨ৎ────────୨ৎ────

<p align="center">
  Cheese v4 right view
</p>

The opposite side provides additional evidence of motor, chassis, sensor, and wiring integration.

---

## ❀ Back View ────୨ৎ────────୨ৎ────

<p align="center">
  Cheese v4 back view
</p>

The rear region contains the main drive architecture.

---

## ❀ Top View ────୨ৎ────────୨ৎ────

<p align="center">
  Cheese v4 top view
</p>

The top view helps explain the distribution of the EV3, motors, sensors, Nano, camera, and wiring.

---

## ❀ Bottom View ────୨ৎ────────୨ৎ────

<p align="center">
  Cheese v4 bottom view
</p>

The bottom view documents the lower chassis, wheel system, steering geometry, and drivetrain support.

---

# ❀ Important v4 Close-Ups ────୨ৎ────────୨ৎ────

## Steering

<p align="center">
  Cheese v4 steering system
</p>

## Large Drive Motor

<p align="center">
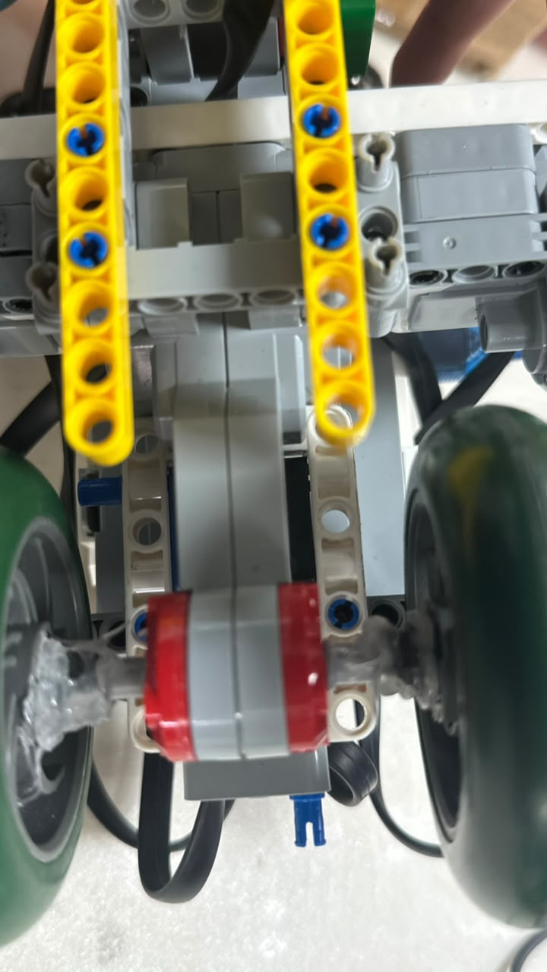
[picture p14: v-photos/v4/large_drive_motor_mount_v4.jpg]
Cheese v4 Large Motor
  
</p>

## Medium Steering Motor

<p align="center">
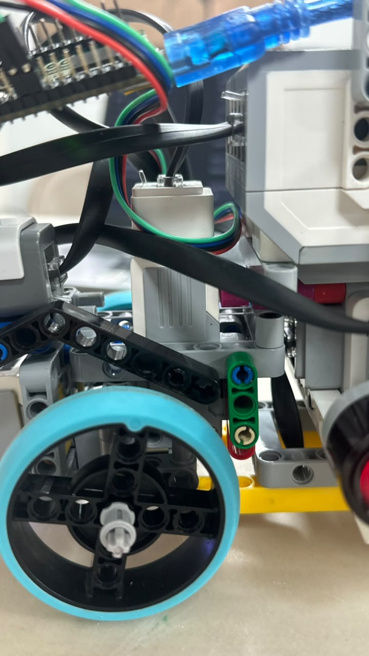
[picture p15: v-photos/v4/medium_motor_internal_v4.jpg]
Cheese v4 Medium Motor
  
</p>

## Front SPIKE Wheels

<p align="center">
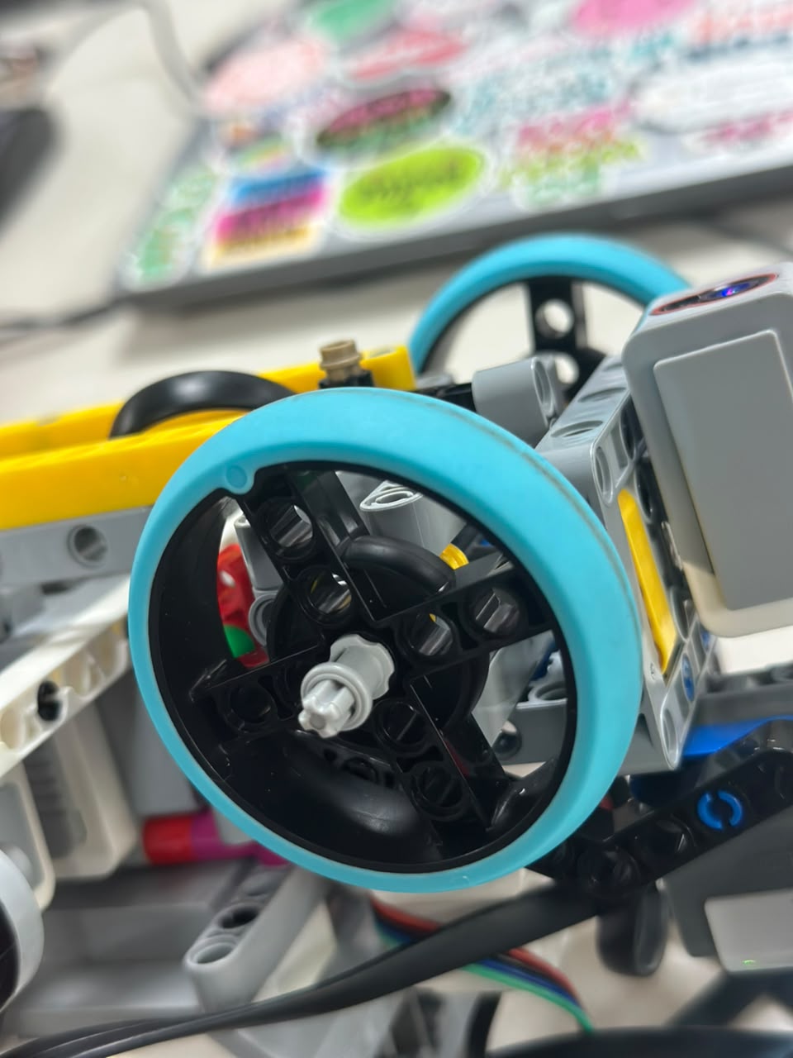
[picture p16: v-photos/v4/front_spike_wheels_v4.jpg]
Cheese v4 front SPIKE wheels
  
</p>

## Wiring

<p align="center">
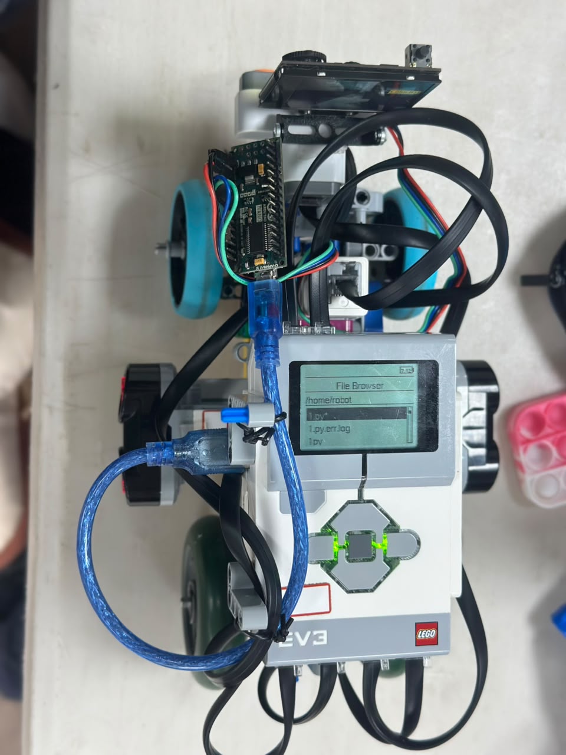
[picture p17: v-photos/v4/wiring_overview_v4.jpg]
Cheese v4 wiring overview
  
</p>

## Arduino Nano

<p align="center">
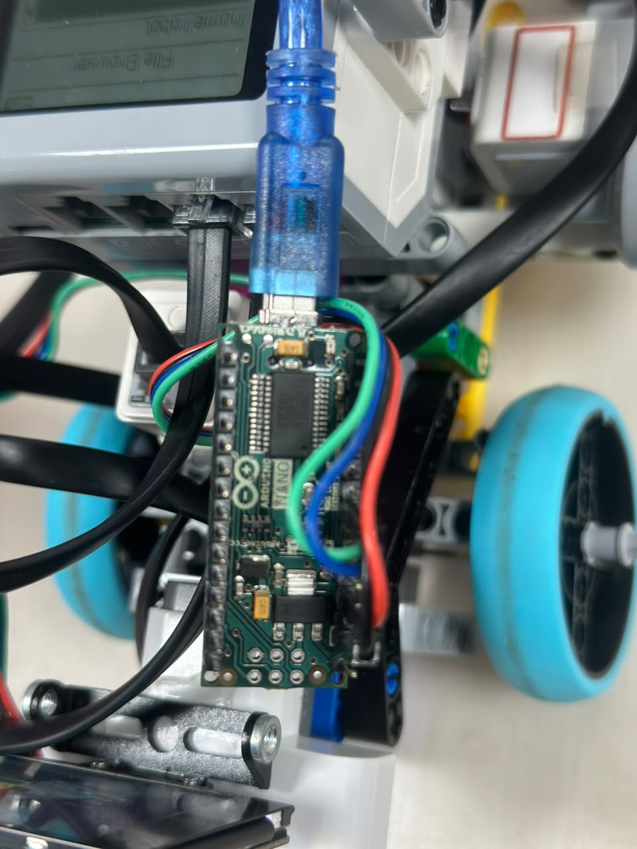
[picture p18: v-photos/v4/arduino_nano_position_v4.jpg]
Cheese v4 Arduino Nano
  
</p>

---

# 📊 Current Development Status

<div align="center">

| System | Status | Main Remaining Work |
| :--- | :---: | :--- |
| **Mechanical v4** | 🟢 Functional | Minor inspection / competition maintenance |
| **Steering** | 🟢 Functional | Continue maintaining alignment |
| **Drive** | 🟢 Functional | Battery-consistency checks |
| **Ultrasonics** | 🟢 Functional | Repeatability / filtering |
| **Color Sensor** | 🟢 Functional | Monitor occasional count issues |
| **Open PID** | 🟢 Functional | Final refinement |
| **Open Curves** | 🟢 Functional | Reduce occasional wide/late cases |
| **3-Lap Open** | 🟢 Mostly reliable | Repeatability |
| **Open Parking** | 🟡 Functional | Final angle / alignment |
| **HuskyLens Detection** | 🟢 Functional | Detection timing |
| **Obstacle Avoidance** | 🟡 In development | Reliability |
| **Post-Obstacle Recovery** | 🟠 Main challenge | Recenter / prepare for next pillar |
| **Obstacle Parking** | 🟠 In progress | Final integration |

</div>
# ᯓ★ Meet the Team ᯓ★

<p align="center">
  
  
  
  
</p>

<p align="center">
  <em>Two students, one robot, many late tests, many changes, and one very determined piece of cheese.</em>
</p>

<p align="center">
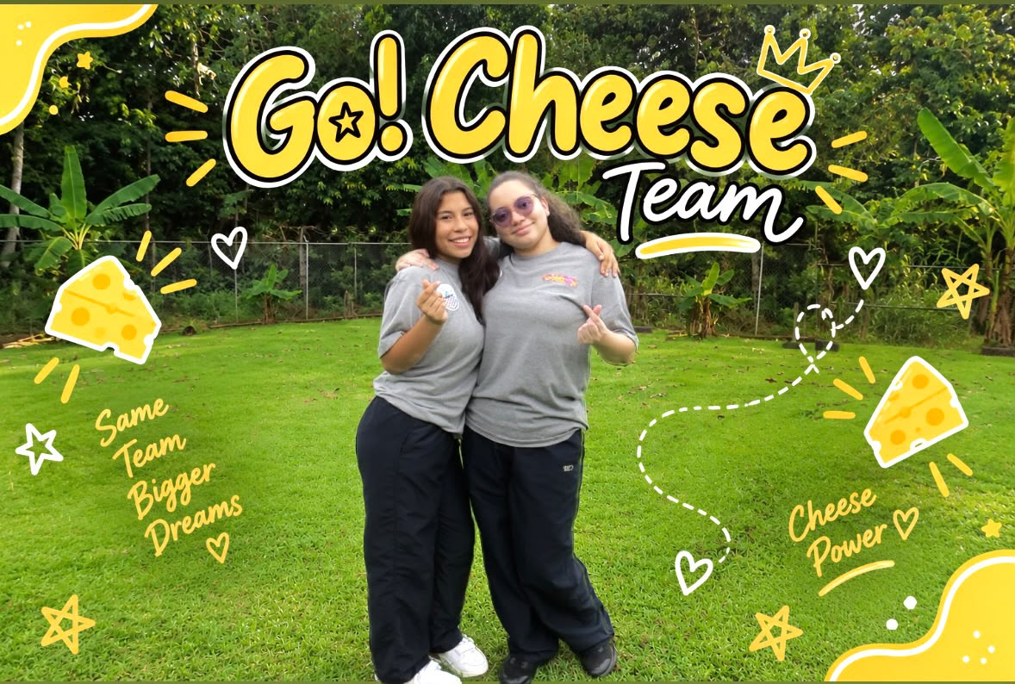
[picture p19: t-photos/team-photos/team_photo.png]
Go!Cheese Team Photo
  
</p>

<p align="center">
  <em>Go!Cheese Team — WRO Future Engineers 2026.</em>
</p>

<p align="center">
  <strong>We are Go!Cheese</strong>, a robotics team of two from San Miguelito, Panama,
  competing in the <strong>WRO Future Engineers 2026</strong> season.
</p>

Our team is built around collaboration, testing, communication, and iteration.

**Romina** focuses primarily on programming, robot building, and physical changes.

**Caylee** focuses primarily on documentation, software explanation, engineering analysis, and organizing the project so another person can understand how Cheese works.

Neither role exists completely independently.

The robot changes influence the documentation.

The documentation forces us to understand the robot.

Testing influences both.

---

## ❀ Team at a Glance ────୨ৎ────────୨ৎ────

<div align="center">

| Member | Main Role | Superpower | Project Focus |
| :---: | :--- | :--- | :--- |
| **Caylee Rios** | Software Explanation & Documentation | Turning ideas, tests, and failures into clear engineering documentation | README structure, logic explanation, tuning analysis, visual organization |
| **Romina Mora** | Programming & Robot Builder | Turning ideas into physical robot changes and functional code | Robot building, code implementation, mechanical adjustments, testing |

</div>

<p align="center">
  <strong>
    Our teamwork connects the story, software, testing, and physical robot.
  </strong>
</p>

---

## ❀ Our Team Dynamic ────୨ৎ────────୨ৎ────

<div align="center">

| What Happens During Testing | How We Work Together |
| :--- | :--- |
| **Cheese crashes into a wall** | We check whether the cause is mechanical, sensor-based, software-based, or related to battery condition. |
| **The curve is too wide or too sharp** | We compare steering behavior, timing, sensor information, and code parameters. |
| **The color sensor misses a marker** | We check sensor position, lighting, color grouping, and curve validation. |
| **A pillar is missed** | We check HuskyLens FOV, robot position, camera angle, speed, and steering response. |
| **Obstacle avoidance works but recovery fails** | We analyze where Cheese finishes the maneuver and how that position affects the next pillar. |
| **Parking becomes inaccurate** | We review curve counting, final distance, timing, alignment, and battery consistency. |
| **The robot improves** | We record the change and the engineering reason behind it. |

</div>

Robotics is not only programming or building.

It requires observing what the real system does and comparing that behavior with what we expected.

---

# ✦ Member Profiles ─── ⋆⋅☆⋅⋆ ───

<p align="center">
  <em>
    Each member has a different focus, but both roles are connected by
    testing, problem-solving, communication, and the same robot.
  </em>
</p>

---

## ❀ Caylee Rios ────୨ৎ────────୨ৎ────

<p align="center">
  
</p>

<p align="center">
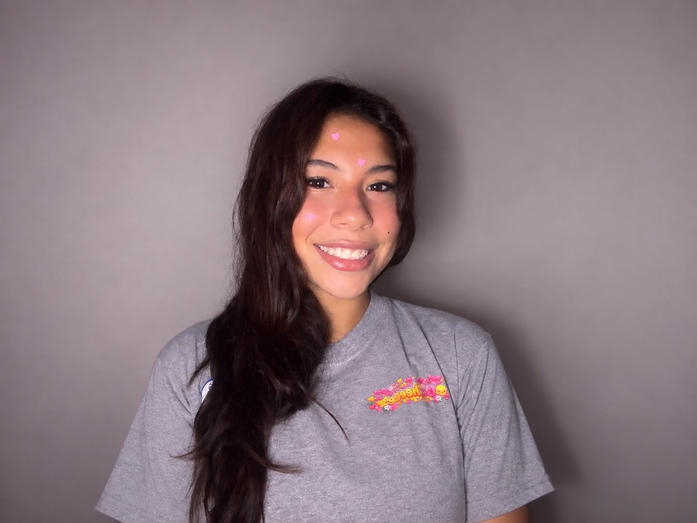
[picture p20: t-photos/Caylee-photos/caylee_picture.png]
Caylee Rios — Go!Cheese
  
</p>

<p align="center">
  <strong>Caylee Rios</strong><br>
  <em>Engineering Documentation & Systems Analysis</em>
</p>

<div align="center">

| Category | Description |
| :--- | :--- |
| **Main Focus** | Documentation, software explanation, engineering reasoning, README structure, and testing analysis |
| **Project Strength** | Turning tests, failures, and robot behavior into understandable engineering explanations |
| **Favorite Part** | Organizing ideas and understanding how Cheese works |
| **Biggest Challenge** | Making sure failures become useful engineering evidence |
| **Main Contribution** | Documentation, project structure, logic explanation, engineering decisions, tuning analysis, and visual organization |

</div>

### About Caylee

Hii! My name is **Caylee**, and this is my first time competing in WRO.

I am really happy to be part of a competition that pushes us toward hard work, problem-solving, and personal growth.

Throughout these two regional competitions, I have grown a lot both as a person and in the way I approach my work as a software engineer. Every test, every good result, and every mistake has taught me something new about how to think, analyze problems, and improve the way we develop Cheese.

We have had many exciting moments, but also many failures, unexpected problems, and difficult tests. Those moments have become some of the most important parts of the experience because we never stop learning from them. We are always curious, always asking questions, and always looking for new things to discover, test, build, and create around robotics.

For me, working on Go!Cheese has been an exciting and very self-challenging experience. It has pushed me to become more patient, more analytical, more creative, and more confident when facing problems that do not have an immediate solution.

One of the things I enjoy the most about robotics is that there is always something else to learn. Every improvement opens the door to another idea, another test, or another challenge, and that constant process of learning and creating is what has made this experience so meaningful to me.

<p align="center">
  <a href="https://www.instagram.com/caymrr">
    
  </a>
</p>

---

## ❀ Romina Mora ────୨ৎ────────୨ৎ────

<p align="center">
  
</p>

<p align="center">
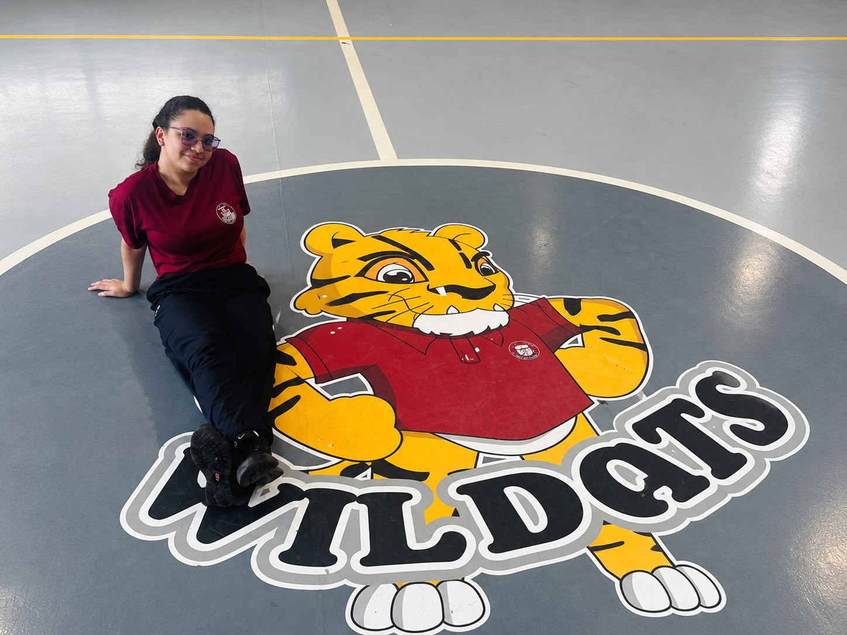
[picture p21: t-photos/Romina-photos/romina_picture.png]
Romina Mora — Go!Cheese
  
</p>

<p align="center">
  <strong>Romina Mora</strong><br>
  <em>Programming & Robot Building</em>
</p>

<div align="center">

| Category | Description |
| :--- | :--- |
| **Main Focus** | Programming, robot building, mechanical changes, software implementation, and testing |
| **Project Strength** | Turning ideas into physical robot changes and functional code |
| **Favorite Part** | Solving challenges through coding, building, and testing |
| **Biggest Challenge** | Adjusting the robot until physical behavior matches the idea in the code |
| **Main Contribution** | Programming, robot construction, mechanism adjustments, code implementation, and physical testing |

</div>

### About Romina

Helloo!!! I’m **Romina**, and I am a very passionate gamer.

I enjoy anything that represents a challenge, and this project has definitely been one of them.

Since 2025, I have been interested in robotics, and in 2026 I finally had the opportunity to work on a real WRO Future Engineers robot.

In Go!Cheese, my role focuses mainly on programming and building.

I help transform ideas into real robot changes, whether that means adjusting the structure, modifying software, testing a behavior, or rebuilding a mechanism.

For me, robotics is exciting because every problem becomes a new challenge to solve.

---

# ❀ How Our Roles Connect ────୨ৎ────────୨ৎ────

<p align="center">
  
  
  
</p>

<div align="center">

| Caylee | Together | Romina |
| :--- | :--- | :--- |
| Organizes documentation | Observe behavior | Builds robot changes |
| Explains software logic | Discuss failures | Programs behavior |
| Records engineering decisions | Compare tests | Adjusts mechanisms |
| Organizes evidence | Choose next experiment | Performs physical testing |
| Connects results to reasoning | Improve Cheese | Implements changes |

</div>

Our roles are different, but they are connected during every development cycle.

When Cheese fails, we do not want the result to disappear.

Instead:

<p align="center">
  <strong>
    OBSERVATION → DISCUSSION → POSSIBLE CAUSE → CHANGE → TEST → RESULT → DOCUMENTATION
  </strong>
</p>

That cycle is the real development process behind Cheese.

---

# ❀ What Go!Cheese Means to Us ────୨ৎ────────୨ৎ────

Go!Cheese is more than the name of our team.

It represents our first serious experience in the WRO Future Engineers category, our learning process, and our determination to keep improving when the robot does not behave how we expected.

Throughout the season, Cheese changed many times.

We:

- redesigned the chassis,
- rebuilt steering systems,
- changed sensor strategies,
- experimented with lighting,
- added vision,
- simplified wiring,
- reduced mass,
- changed wheel configurations,
- tuned PID,
- changed curve behavior,
- developed parking,
- developed obstacle avoidance,
- and documented the reasoning behind those changes.

Every version taught us something.

<p align="center">
  <strong>
    For us, Go!Cheese means learning by doing, improving through testing,
    and proving that a small team can still build something meaningful
    with creativity, discipline, and teamwork.
  </strong>
</p>

---

## ❀ Same Team, Bigger Dreams ────୨ৎ────────୨ৎ────

<p align="center">
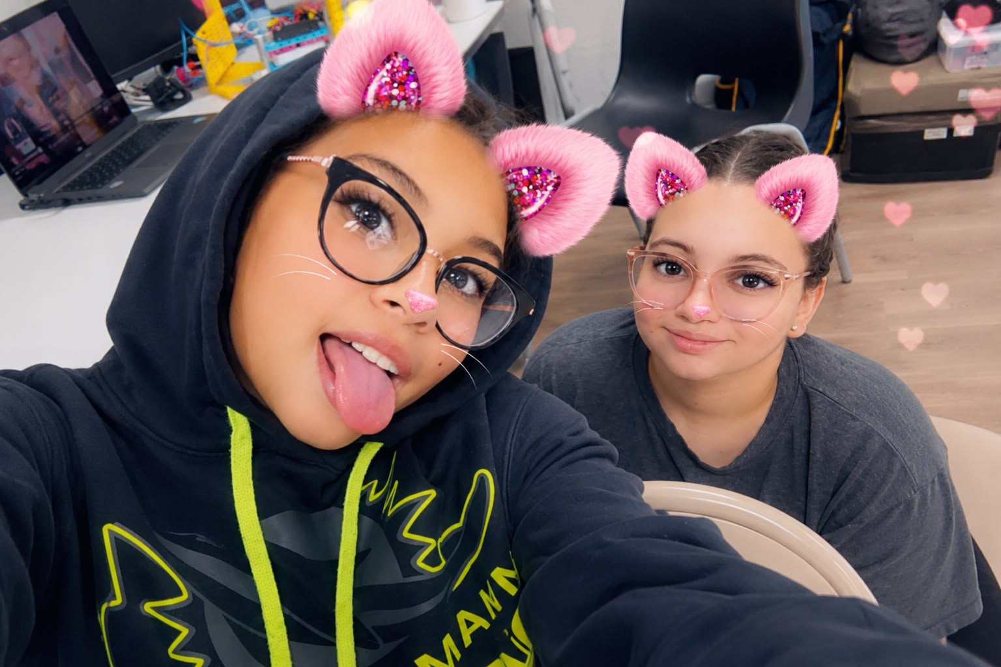
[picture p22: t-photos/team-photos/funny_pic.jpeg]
Go!Cheese Funny Team Photo
  
</p>

<p align="center">
  <em>Same Team. Bigger Dreams.</em>
</p>

Not every part of the project happens in front of a computer or on the competition field.

This photo is part of our documentation because Go!Cheese is also about the experience behind the engineering: long testing sessions, failed runs, successful improvements, learning together, and enjoying the process.

---

# ❀ Team Motto ────୨ৎ────────୨ৎ────

<p align="center">
  ✦ ─── ⋆⋅☆⋅⋆ ─── (❁´◡`❁) ─── ⋆⋅☆⋅⋆ ─── ✦
</p>

<p align="center">
  <strong>
    “Build it, test it, break it, fix it, and make it better.”
  </strong>
</p>

<p align="center">
  <em>
    One robot, two minds, many tests, and a lot of cheese-powered determination.
  </em>
</p>

---

<h2 align="center">🧀 Why "Cheese"? 🧀</h2>

<p align="center">
  <em>"From a childhood rhyme to the competition track."</em>
</p>

<div align="center">

────────୨ৎ────────

</div>

Our name comes from a little recess rhyme we used to play back when we were kids.

It always stuck with us, so when it came time to choose our team name, we picked something that carried a piece of that memory with us.

That is how **Go!Cheese** was born.

It reminds us of where we started and of the season of our lives we are living now.

Our robot is named **Cheese** as a pun on our team name.

The idea is simple, and it became the heart of the project:

<p align="center">
  <strong>Cheese is the one who goes.</strong>
</p>

<div align="center">

────────୨ৎ────────

</div>

---

<h2 align="center">🧀 Go!Cheese — WRO Future Engineers 2026 🧀</h2>

<p align="center">
  <strong>
    Designed through failures.<br>
    Improved through testing.<br>
    Explained through engineering.
  </strong>
</p>

<p align="center">
  ✦ ─── ⋆⋅☆⋅⋆ ─── (❁´◡`❁) ─── ⋆⋅☆⋅⋆ ─── ✦
</p>
---

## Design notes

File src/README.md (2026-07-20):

# ᯓ★ Source Code Documentation ᯓ★

<p align="center">
  
  
  
</p>

<p align="center">
  <em>This folder contains the program files developed for Cheese during the WRO Future Engineers 2026 season. The files are organized by challenge type and development stage, showing how the robot’s logic evolved through testing, failures, tuning, and redesign.</em>
</p>

<p align="center">
  ✦ ─── ⋆⋅☆⋅⋆ ─── (❁´◡`❁) ─── ⋆⋅☆⋅⋆ ─── ✦
</p>

---

## ❀ Folder Purpose ────୨ৎ────────୨ৎ────

The `src/` folder is used to store Cheese’s code versions. Instead of keeping only one final program, we kept different versions to document the development process. This helps show how the robot’s software changed as we tested different movement strategies, curve methods, sensor logic, and stopping systems.

Not every file in this folder is meant to be used as a final competition program. Some files are experimental, some are older versions, and some were kept as evidence of what was tested before reaching the current logic.

This is important because Cheese’s final behavior was not created in one attempt. The code evolved through repeated testing, including problems with wall following, curve detection, color readings, parking accuracy, obstacle detection, and code complexity.

---

## ❀ Code Folder Overview ────୨ৎ────────୨ৎ────

<div align="center">

| Folder | Status | Purpose |
| :--- | :--- | :--- |
| **`code_open/`** | Main development folder | Contains the Open Challenge code versions used to test wall following, curve detection, lap counting, and final stopping behavior. |
| **`code_obstacles/`** | Broken / incomplete | Contains obstacle-related experiments. This folder is not considered final because the obstacle code was still unstable and not ready for reliable competition use. |
| **`v2 coding/`** | Older version | Contains earlier PID and stopping logic from the v2 development stage. It is kept as evidence of the code evolution before Cheese v3. |

</div>

---

## ❀ Open Challenge Code Logic ────୨ৎ────────୨ৎ────

The most developed logic is inside the `code_open/` folder. These files focus on the **Open Challenge**, where Cheese must drive around the track without obstacles, complete the required laps, detect curves, and stop after the run.

The general Open Challenge logic follows this structure:

```text
1. Initialize motors and sensors.
2. Wait for the start command.
3. Read ultrasonic sensors and color sensor.
4. Use PID or wall correction to stay between the walls.
5. Detect floor colors used for curve tracking.
6. Confirm color readings before accepting them.
7. Count completed curves using color logic.
8. Track lap progress through curve count.
9. Activate final stopping logic after the required progress.
10. Stop the robot safely.
```

This structure helped separate the robot’s behavior into different responsibilities. Ultrasonic sensors support wall awareness, the color sensor supports curve counting, and the drive/steering motors execute the movement decisions.

---

## ❀ Main Behavior Layers ────୨ৎ────────୨ৎ────

Cheese’s software does not rely on only one control behavior. Instead, it uses several behavior layers that work together.

<div align="center">

| Behavior Layer | Purpose |
| :--- | :--- |
| **Normal PID Driving** | Keeps Cheese centered between the walls during stable movement. |
| **Wall Protection** | Overrides normal movement when the robot gets too close to a wall. |
| **Color Detection** | Reads floor markers used to identify curve progress. |
| **Curve Counting** | Tracks completed curves and connects them to lap progress. |
| **Post-Curve Recovery** | Helps the robot stabilize after completing a curve. |
| **Final Stop Logic** | Stops the robot after the required Open Challenge progress is completed. |

</div>

This layered structure was necessary because one behavior alone was not reliable enough. PID helped with normal driving, but it could not solve every situation. Wall protection was needed when Cheese got too close to a wall. Color logic was needed to track progress. Recovery was needed because the robot often exited curves at difficult angles.

---

## ❀ Code Evolution ────୨ৎ────────୨ৎ────

The code evolved through many tests. Early versions focused mainly on basic movement and PID correction. Later versions added curve detection, color logic, wall protection, lap counting, and final stopping behavior.

<div align="center">

| Stage | Main Focus | What Changed |
| :--- | :--- | :--- |
| **Early PID versions** | Basic wall following | The robot used ultrasonic readings to stay between walls, but the movement was not always consistent after curves. |
| **v2 code** | PID with stopping attempts | Older logic tested basic stopping and control behavior, but it was not reliable enough for the final robot. |
| **Open Challenge experiments** | Curve detection and lap tracking | Different versions tested how to count curves, detect colors, and connect curve progress to the final stop. |
| **Color-based curve versions** | Blue/orange marker detection | The color sensor was used to detect floor markers and improve curve counting. |
| **Tuning versions** | Stability and reliability | Speed, steering response, wall protection, color confirmation, and curve logic were adjusted through repeated tests. |
| **Obstacle experiments** | Camera-based obstacle detection | Early obstacle code was tested but kept separate because it was unstable and not final. |

</div>

The code history shows that Cheese’s software was developed through trial, testing, and correction. Each version helped identify what needed to change.

---

## ❀ Open Challenge Version Notes ────୨ৎ────────୨ৎ────

The `code_open/` folder contains several versions. These files should be understood as part of the testing history, not as identical final programs.

<div align="center">

| File / Version | Purpose |
| :--- | :--- |
| **`7.py`** | Earlier Open Challenge experiment. Kept as part of the code history. |
| **`14.py`** | Open Challenge testing version used during development. |
| **`15.py`** | Main experimental branch for color sensor curves, steering behavior, and navigation improvements. |
| **`18.py`** | Additional Open Challenge test version. |
| **`19.py`** | Later Open Challenge test version, used during curve and movement experiments. |
| **`A2.py`** | Alternative test version for Open Challenge behavior. |
| **`A3.py`** | Alternative test version for Open Challenge behavior. |
| **`15_open_color_sensor_curves_rear_us_reference_...`** | Experimental version involving color-sensor curve logic and rear ultrasonic reference ideas. This is kept as evidence, but it is not the main documented final strategy. |

</div>

Because several files were created during testing, the most important thing is not the file number alone, but the logic being tested inside each version. Some versions focused on curves, others on parking, and others on sensor behavior.

---

## ❀ Obstacle Code Status ────୨ৎ────────୨ৎ────

The `code_obstacles/` folder is currently marked as **broken / incomplete**.

This folder contains obstacle-related experiments, but it is not considered a final working version. The obstacle challenge required stable red and green obstacle detection, lighting support, camera communication, and safe avoidance behavior. During testing, this logic was harder to stabilize because the HuskyLens camera was affected by lighting conditions and recognition consistency.

For this reason, the obstacle code is kept in the repository as development evidence, but it should not be used as the final reference for a reliable competition run.

<div align="center">

| Obstacle Code Area | Status |
| :--- | :--- |
| **Obstacle recognition** | Experimental |
| **Camera-based decision logic** | Not fully stable |
| **Avoidance movement** | Still needs refinement |
| **Lighting dependency** | Requires more calibration |
| **Final reliability** | Not final |

</div>

The obstacle strategy is documented in the software section, but the actual obstacle code remains under development.

Related documentation:

<div align="center">

| Document | Link |
| :--- | :--- |
| **Obstacle Challenge** | [Open Document](../sections/03-software-and-obstacle-strategy/3.4-obstacle-challenge.md) |
| **Sensor Calibration** | [Open Document](../sections/02-power-and-sensor-architecture/2.4-sensor-calibration.md) |
| **Tuning Process** | [Open Document](../sections/03-software-and-obstacle-strategy/3.6-tuning-process.md) |

</div>

---

## ❀ Main Open Challenge Logic Summary ────୨ৎ────────୨ৎ────

The Open Challenge code is based on the idea that Cheese needs to drive, correct, detect, count, and stop in a controlled order.

```text
Start
 ↓
Initialize sensors and motors
 ↓
Begin movement
 ↓
Read ultrasonic sensors
 ↓
Read color sensor
 ↓
Choose behavior:
   - Normal PID driving
   - Wall protection
   - Curve handling
   - Post-curve recovery
 ↓
Confirm color events
 ↓
Count completed curves
 ↓
Check lap progress
 ↓
Activate final stop logic
 ↓
Stop
```

This logic connects the robot’s physical movement to its software state. Cheese does not simply drive forward; it continuously reacts to sensor readings and updates its internal progress.

---

## ❀ Why the Code Needed Many Versions ────୨ৎ────────୨ৎ────

The code needed many versions because the robot’s real behavior changed depending on the track, lighting, sensor readings, steering angle, and speed. A value that worked in one test could fail in another.

Some of the main problems we tried to solve through code changes were:

<div align="center">

| Problem | Why It Mattered |
| :--- | :--- |
| **Curves too wide or too sharp** | A bad curve angle could cause Cheese to hit a wall after the turn. |
| **Color sensor inconsistency** | If the robot missed a marker, the curve count became wrong. |
| **Parking descalibration** | If the robot counted wrong or stopped late, it did not finish where expected. |
| **Wall correction too aggressive** | Strong corrections could make the robot zig-zag or hit the opposite wall. |
| **Wall correction too weak** | Weak corrections could allow the robot to drift into the wall. |
| **Obstacle detection instability** | Irregular lighting affected camera recognition. |
| **Code complexity** | Long code made it harder to debug and tune specific behaviors. |

</div>

Because of these problems, the code was adjusted gradually. We changed values, tested the robot again, observed the behavior, and kept improving.

---

## ❀ Final Software Direction ────୨ৎ────────୨ৎ────

The final software direction for Cheese prioritizes **clear behavior layers** instead of one large, confusing control structure.

The most important software decisions were:

```text
Use ultrasonic sensors for wall awareness.
Use PID for normal centering.
Use wall protection when the robot is too close to walls.
Use the color sensor to support curve counting.
Use confirmation logic to reduce false color readings.
Use curve count as a progress reference.
Use final stop logic after the required run progress.
Keep obstacle code separate until it becomes stable.
```

This approach made the software easier to test and explain. It also made the documentation stronger because each behavior has a clear purpose.

---

## ❀ Related Documentation ────୨ৎ────────୨ৎ────

For a deeper explanation of Cheese’s software and testing process, visit these sections:

<div align="center">

| Section | Link |
| :--- | :--- |
| **3.0 Cheese Logic Overview** | [Open Document](../sections/03-software-and-obstacle-strategy/3.0%20Cheese%20Logic%20Overview.md) |
| **3.1 Algorithm Architecture** | [Open Document](../sections/03-software-and-obstacle-strategy/3.1-algorithm-architecture.md) |
| **3.2 Flowchart** | [Open Document](../sections/03-software-and-obstacle-strategy/3.2-flowchart.md) |
| **3.3 Open Challenge** | [Open Document](../sections/03-software-and-obstacle-strategy/3.3-open-challenge.md) |
| **3.4 Obstacle Challenge** | [Open Document](../sections/03-software-and-obstacle-strategy/3.4-obstacle-challenge.md) |
| **3.5 Corner Handling** | [Open Document](../sections/03-software-and-obstacle-strategy/3.5-corner-handling.md) |
| **3.6 Tuning Process** | [Open Document](../sections/03-software-and-obstacle-strategy/3.6-tuning-process.md) |

</div>

---

## ❀ Final Note ────୨ৎ────────୨ৎ────

The `src/` folder is not only a place to store code. It shows the evolution of Cheese’s logic across the season. Each version represents a test, an adjustment, or a problem that helped guide the next improvement.

<p align="center">
  <strong>The final code direction for Cheese is based on testing, simplification, sensor feedback, curve counting, and controlled behavior priorities.</strong>
</p>

<p align="center">
  ✦ ─── ⋆⋅☆⋅⋆ ─── (❁´◡`❁) ─── ⋆⋅☆⋅⋆ ─── ✦
</p>

<p align="center">
  <a href="../README.md">
    
  </a>
</p>

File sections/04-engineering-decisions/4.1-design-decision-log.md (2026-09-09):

<h1 align="center">ᯓ★ 4.1 Design Decision Log ᯓ★</h1>

<p align="center">
  
  
  
  
</p>

<p align="center">
  <em>
    Cheese v4 was not created by adding more components.
    It was created by identifying which parts actually improved performance,
    removing unnecessary complexity, and redesigning the robot around
    reliability, accessibility, sensor quality, and easier calibration.
  </em>
</p>

<p align="center">
  ✦ ─── ⋆⋅☆⋅⋆ ─── 🧀⚙️ ─── ⋆⋅☆⋅⋆ ─── ✦
</p>

---

A design decision is more than a physical modification.

For Go!Cheese, a decision becomes an engineering decision when it can be connected to:

<p align="center">
  <strong>
    Observation → Problem → Decision → Trade-Off → Test → Result → Learning
  </strong>
</p>

The transition from Cheese v3 to Cheese v4 followed this process repeatedly.

Instead of solving every problem by adding another support, sensor mount, cable holder, or structural piece, we began asking a different question:

<p align="center">
  <strong>
    Does this component directly improve the function of the robot?
  </strong>
</p>

This question became one of the main principles behind Cheese v4.

---

# ❀ 4.1.1 Purpose of the Design Decision Log ────୨ৎ────────୨ৎ────

The purpose of this section is to explain **why Cheese looks and behaves the way it does today**.

The final robot alone does not show the complete engineering process.

A judge can see the finished chassis, sensors and wiring, but those elements do not automatically explain:

- why the robot became lighter,
- why the EV3 Brick was lowered,
- why the camera structure changed,
- why the ultrasonic sensors were repositioned,
- why the front wheels changed,
- why auxiliary lighting disappeared,
- or why some working components were intentionally left almost unchanged.

This section therefore documents four important questions.

<div align="center">

| Engineering Question | Purpose |
| :--- | :--- |
| **What problem did we observe?** | Connect the decision to real testing |
| **What did we change?** | Identify the engineering response |
| **What trade-off did we accept?** | Show that every decision has consequences |
| **How did it affect the complete robot?** | Demonstrate systems thinking |

</div>

The objective is not to present v4 as a perfect robot.

The objective is to show how testing progressively produced a better one.

---

# ❀ 4.1.2 Our Systems-Thinking Approach ────୨ৎ────────୨ৎ────

One of the biggest lessons during development was that Cheese cannot be divided into completely independent systems.

A mechanical modification can affect software.

A sensor modification can affect steering.

A battery condition can change how the same software behaves physically.

A camera position can change how much reaction time the obstacle algorithm receives.

For Cheese, the interaction can be summarized as:

<p align="center">
  <strong>
    Structure → Sensor Geometry → Sensor Data → Software Decision → Motor Response → Robot Motion → New Sensor Data
  </strong>
</p>

This creates a continuous feedback system.

<div align="center">

| Subsystem | Can Affect | Example on Cheese |
| :--- | :--- | :--- |
| **Mechanical structure** | Mass, rigidity, sensor alignment | Excess structure increased mass and complexity |
| **Sensor placement** | Measurement quality | Ultrasonic position changes wall readings |
| **Vision placement** | Detection timing | HuskyLens angle changes when a pillar enters view |
| **Power** | Motor response | Battery condition changes physical reaction |
| **Steering geometry** | Curve behavior | Ackermann geometry determines the physical turn |
| **Software** | Corrections and recovery | PID determines when and how strongly Cheese reacts |
| **Testing** | Future decisions | Failures reveal which subsystem needs modification |

</div>

The central lesson became:

<p align="center">
  <strong>
    When one subsystem changes, the behavior of the complete robot can change with it.
  </strong>
</p>

---

# ❀ 4.1.3 Main Design Constraints ────୨ৎ────────୨ৎ────

Cheese v4 was developed under real engineering constraints.

<div align="center">

| Constraint | Effect on the Design |
| :--- | :--- |
| **Competition rules** | The design must support autonomous navigation, obstacle behavior and parking |
| **Available LEGO components** | Solutions must use parts that are actually available to the team |
| **Limited testing time** | Changes must be practical to build and validate |
| **Robot mass** | Unnecessary structure increases inertia and motor load |
| **Mechanical rigidity** | Removing too much structure can create flex |
| **Sensor reliability** | Sensors must be positioned for useful measurements |
| **Camera visibility** | HuskyLens must see pillars early enough to react |
| **Wiring access** | Components must remain inspectable and repairable |
| **Battery condition** | Physical response can change as available power changes |
| **Calibration time** | Every unnecessary redesign can introduce new variables |

</div>

These constraints pushed v4 toward a simpler philosophy:

<p align="center">
  <strong>
    Keep what works → Remove what does not help → Improve what limits reliability
  </strong>
</p>

---

# ❀ 4.1.4 From Cheese v3 to Cheese v4 ────୨ৎ────────୨ৎ────

The redesign from v3 to v4 was substantial.

The previous v3 robot had a measured mass of **888.8 g**, commonly rounded to approximately **888 g** in the documentation.

Cheese v4 has a measured mass of **666 g**.

This represents a reduction of approximately:

<p align="center">
  <strong>
    888.8 g → 666 g = 222.8 g removed
  </strong>
</p>

That is approximately **25% of the v3 mass**.

But the redesign involved much more than weight.

<p align="center">
  Structural components removed during Cheese v3 to v4 redesign
</p>

<p align="center">
  <em>
    Structural components removed while simplifying Cheese from v3 to v4.
    Parts were removed selectively rather than randomly.
  </em>
</p>

<p align="center">
  Lighting system removed during Cheese v3 to v4 redesign
</p>

<p align="center">
  <em>
    Auxiliary lighting hardware from the previous configuration was also removed
    as the vision system and physical layout evolved.
  </em>
</p>

The main redesign decisions were:

<div align="center">

| Design Area | v3 | v4 | Main Reason |
| :--- | :--- | :--- | :--- |
| **Mass** | 888.8 g | 666 g | Reduce unnecessary load |
| **Overall structure** | Taller and more complex | Lower and more compact | Improve accessibility and reduce excess structure |
| **EV3 position** | More integrated into upper structure | Lower and flatter | Lower mass distribution and improve access |
| **Large Motor** | Previous mounting layout | Horizontal mounting | Fit compact architecture |
| **Camera support** | Larger upper structure | Simplified | Remove unnecessary mass |
| **HuskyLens position** | Higher | Lower and forward | Improve compactness and field view |
| **Auxiliary lights** | Present | Removed | No longer part of current v4 architecture |
| **Ultrasonic layout** | Earlier placement | Three-sensor layout | Improve wall and forward awareness |
| **Front wheels** | Previous LEGO wheel setup | SPIKE front wheels | Improve front contact during steering |
| **Nano USB** | Longer cable | Shorter cable | Reduce wiring clutter |

</div>

This redesign established the physical foundation for the current software calibration.

---

# ❀ 4.1.5 Decision 01 — Reduce Robot Mass ────୨ৎ────────୨ৎ────

### Problem

Cheese v3 contained structural elements that had accumulated during earlier development.

Some were necessary when they were introduced, but later versions no longer depended on all of them.

The result was additional mass and complexity.

### Decision

Remove components that no longer served a clear structural, sensing, wiring, or protective purpose.

<p align="center">
  <strong>
    v3: 888.8 g → v4: 666 g
  </strong>
</p>

<div align="center">

| Measurement | Value |
| :--- | :---: |
| **Cheese v3** | **888.8 g** |
| **Cheese v4** | **666 g** |
| **Mass removed** | **222.8 g** |
| **Approximate reduction** | **25%** |

</div>

### Engineering reasoning

For the same propulsion system, reducing unnecessary mass reduces the inertia that must be accelerated, redirected and stopped.

This is especially relevant when Cheese:

- enters a corner,
- changes steering direction,
- performs a PID correction,
- reverses during recovery,
- or slows during parking.

### Trade-off

Removing structure can reduce rigidity.

The goal was therefore **not minimum possible weight**.

The goal was:

<p align="center">
  <strong>
    Minimum unnecessary weight while preserving sufficient structural rigidity.
  </strong>
</p>

### Result

The final v4 structure became substantially lighter and easier to inspect while maintaining the components required for competition operation.

---

# ❀ 4.1.6 Decision 02 — Lower and Simplify the Main Structure ────୨ৎ────────୨ৎ────

Weight was not the only reason for rebuilding the chassis.

The location of that weight also mattered.

<p align="center">
  Cheese v4 final compact structure
</p>

<p align="center">
  <em>
    Current Cheese v4 showing the lower and more compact final architecture.
  </em>
</p>

The EV3 Brick was positioned lower and flatter, with the screen facing upward.

The Large Motor was also integrated horizontally into the current layout.

These decisions helped create a robot that is:

- more compact,
- easier to access,
- easier to inspect,
- and less dependent on a tall upper structure.

<p align="center">
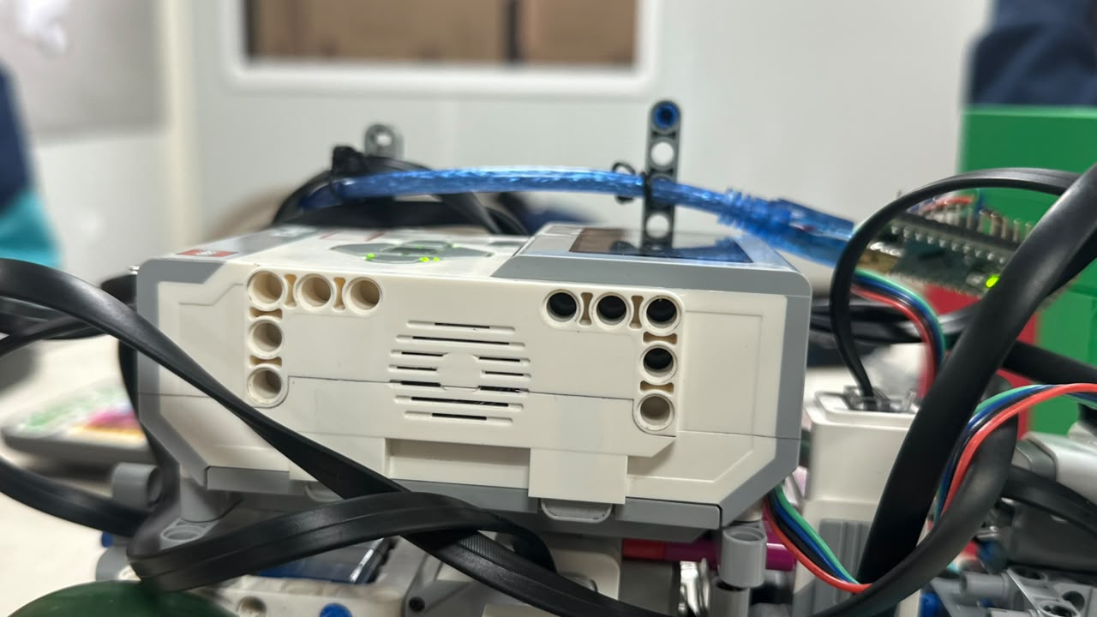
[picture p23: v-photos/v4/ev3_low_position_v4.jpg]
Lower EV3 Brick position on Cheese v4
  
</p>

<p align="center">
  <em>
    Lower EV3 placement used in the current v4 architecture.
  </em>
</p>

### Trade-off

A compact structure provides less unused internal space.

This means component placement must be planned more carefully.

### Why we accepted it

The team preferred a deliberate compact layout over keeping empty structure only because it made mounting easier.

---

# ❀ 4.1.7 Decision 03 — Simplify the HuskyLens Structure ────୨ৎ────────୨ৎ────

The HuskyLens remained necessary for the Obstacle Challenge.

The large structure previously surrounding it did not.

### Problem

The v3 camera arrangement contributed:

- upper mass,
- additional supports,
- wiring complexity,
- and a taller robot profile.

### Decision

Keep the HuskyLens facing forward while simplifying its surrounding structure and lowering its position.

<p align="center">
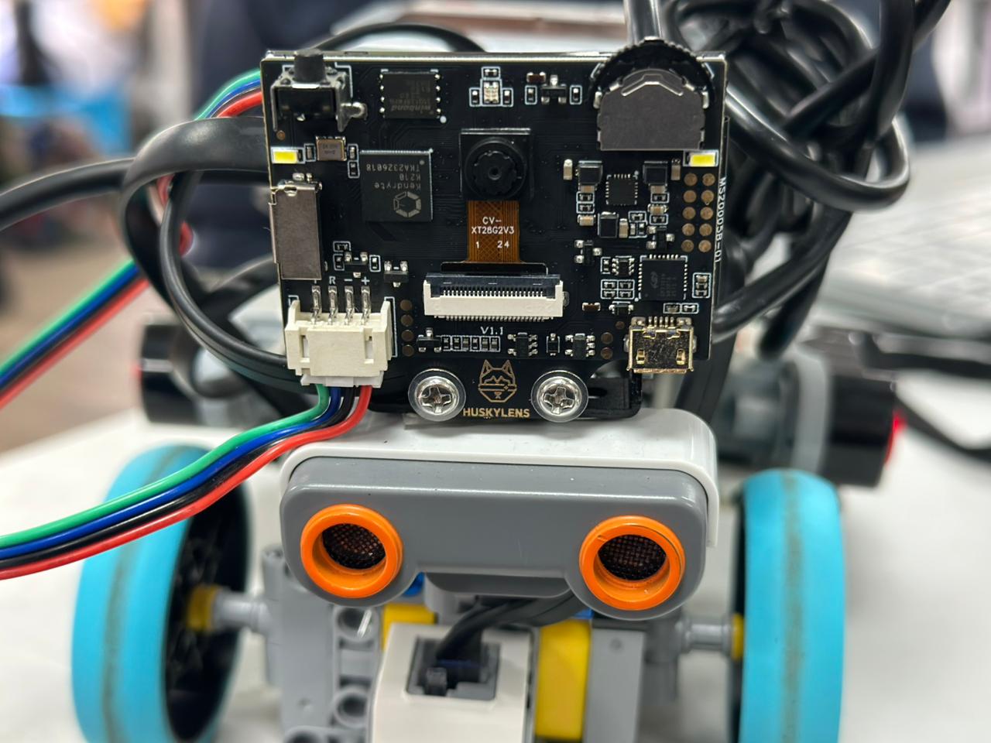
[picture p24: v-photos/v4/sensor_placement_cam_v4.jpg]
Current HuskyLens position on Cheese v4
  
</p>

<p align="center">
  <em>
    Current forward HuskyLens position in Cheese v4.
  </em>
</p>

<p align="center">
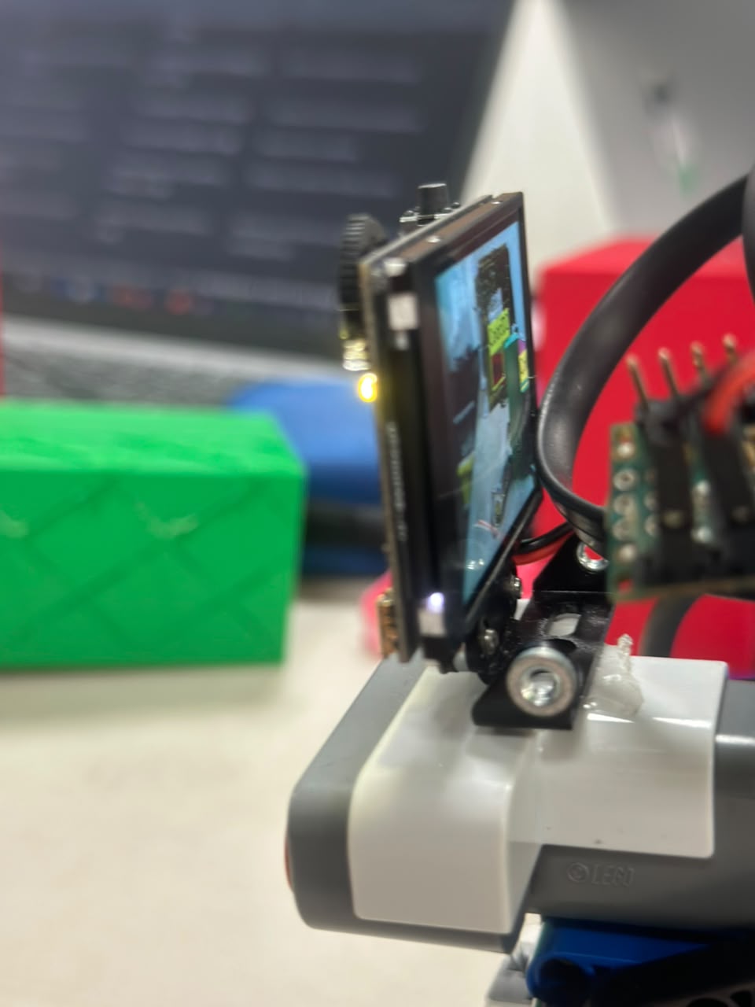
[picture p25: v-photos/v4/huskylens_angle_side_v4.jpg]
Side view of Cheese v4 HuskyLens angle
  
</p>

<p align="center">
  <em>
    Side view used to evaluate the current HuskyLens height and viewing angle.
  </em>
</p>

### System effect

Camera placement affects much more than image quality.

<p align="center">
  <strong>
    Camera Height + Camera Angle → Detection Timing → Available Reaction Distance → Obstacle Avoidance
  </strong>
</p>

A pillar detected correctly but too late can still produce a failed maneuver.

### Trade-off

A lower camera requires careful angle calibration so that the field of view remains useful.

### Current result

The current HuskyLens configuration can recognize the competition pillar colors.

Current training uses:

<div align="center">

| Pillar | HuskyLens ID | Required Passing Side |
| :--- | :---: | :---: |
| 🟢 **Green** | **Color ID 1** | **Left** |
| 🔴 **Red** | **Color ID 2** | **Right** |

</div>

The remaining Obstacle Challenge problem is therefore not simply color recognition.

It is reliably converting detection into avoidance and recovery.

---

# ❀ 4.1.8 Decision 04 — Remove the Auxiliary Lighting System ────୨ৎ────────୨ৎ────

Cheese v3 used additional lighting hardware around the sensing area.

The current v4 architecture does **not** use those auxiliary lights.

### Decision

Remove:

- the lights,
- their structural supports,
- associated mounting pieces,
- and the additional power-support structure that was no longer required.

### Why

The v4 camera position and sensing configuration changed enough that maintaining the previous lighting structure was no longer justified by its cost in mass and complexity.

### Trade-off

Removing controlled lighting means ambient conditions must still be considered during testing.

### Result

The front structure became simpler and lighter.

This is a good example of a component being useful in one version but unnecessary in the next.

<p align="center">
  <strong>
    A previous solution does not need to remain forever if the original problem changes.
  </strong>
</p>

---

# ❀ 4.1.9 Decision 05 — Improve Ultrasonic Sensor Placement ────୨ৎ────────୨ৎ────

The Open Challenge depends heavily on ultrasonic measurements.

Cheese v4 uses:

- a left ultrasonic sensor,
- a right ultrasonic sensor,
- and a front ultrasonic sensor.

<p align="center">
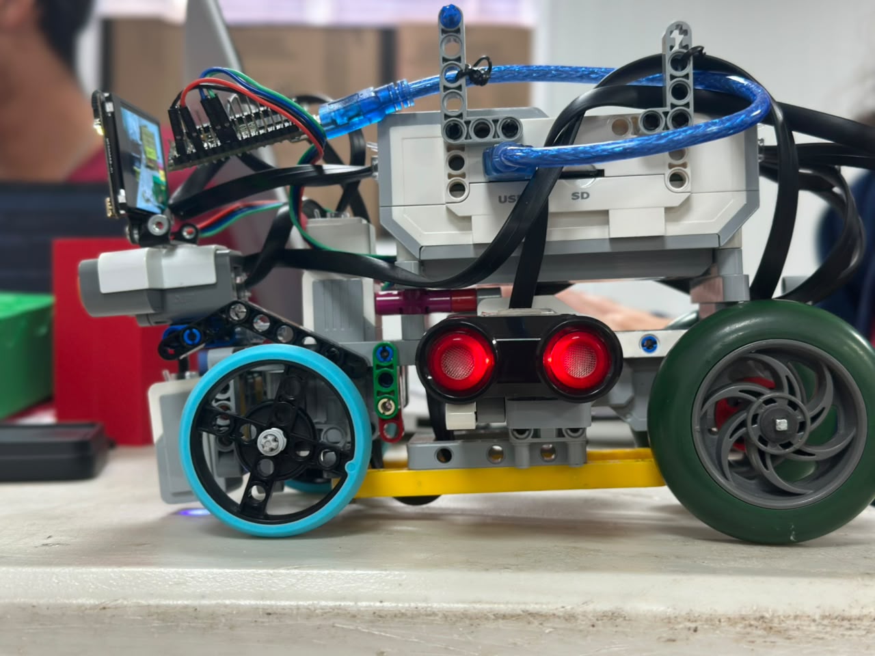
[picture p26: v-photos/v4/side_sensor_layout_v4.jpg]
Cheese v4 lateral ultrasonic sensor layout
  
</p>

<p align="center">
  <em>
    Current side-sensor layout used for wall-distance information.
  </em>
</p>

### Problem

Software cannot produce reliable wall correction if the physical measurements entering the controller are unreliable.

### Decision

Position the lateral ultrasonic sensors lower and directly toward the side walls while maintaining a front ultrasonic for forward safety.

<div align="center">

| Sensor | Main Function |
| :--- | :--- |
| **Left Ultrasonic** | Left-side distance |
| **Right Ultrasonic** | Right-side distance |
| **Front Ultrasonic** | Forward clearance and recovery support |

</div>

### Engineering reasoning

The order of improvement should be:

<p align="center">
  <strong>
    Better Sensor Geometry → Better Measurements → Better PID Input → Better Steering Decision
  </strong>
</p>

not:

<p align="center">
  <strong>
    Poor Measurement → More Aggressive Software → More Instability
  </strong>
</p>

### Trade-off

Lower sensors can be physically more exposed.

### Why we accepted it

Wall-distance quality is fundamental to Open navigation, so measurement quality was prioritized.

---

# ❀ 4.1.10 Decision 06 — Preserve the Working Color-Sensor Architecture ────୨ৎ────────୨ৎ────

Not every v4 decision involved replacing something.

The color sensor already had a useful floor-facing structural position.

<p align="center">
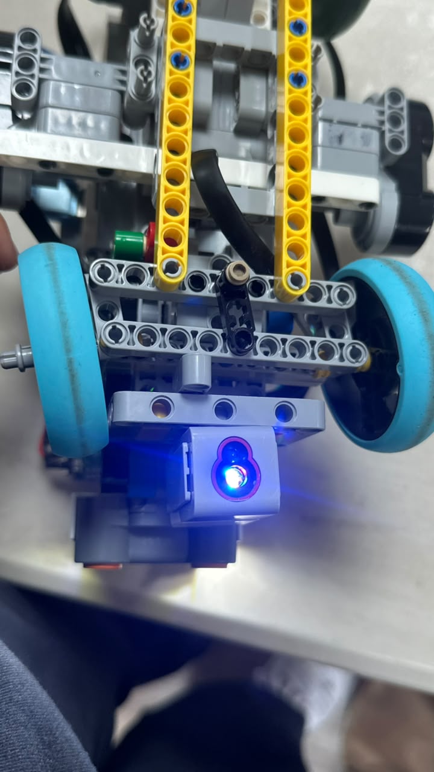
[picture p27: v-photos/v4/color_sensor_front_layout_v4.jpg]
Cheese v4 color sensor position
  
</p>

<p align="center">
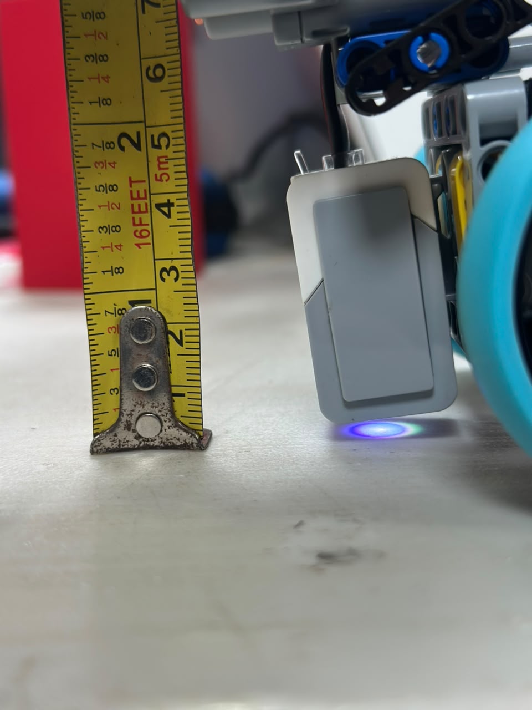
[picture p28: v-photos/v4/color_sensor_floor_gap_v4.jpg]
Cheese v4 color sensor floor gap
  
</p>

In v4, the sensor remained in the same **general structural location**, while its floor gap was adjusted slightly lower to improve detection.

### Earlier problem

Ambient lighting affected floor-color recognition during earlier testing.

An improvised light-blocking cover was tested.

However, the cover could drag against the field and created a new mechanical problem.

### Decision

Remove the dragging cover and improve the sensor's physical floor distance instead.

### Result

The current sensor position provides sufficiently improved detection that an external light-blocking cover is not part of normal v4 operation.

This produced an important lesson:

<p align="center">
  <strong>
    A fix that solves one problem but creates another is not automatically a good engineering solution.
  </strong>
</p>

---

# ❀ 4.1.11 Decision 07 — Change Only the Front Wheels ────୨ৎ────────୨ৎ────

Cheese v4 changed the **front wheels** to LEGO SPIKE wheel assemblies.

The rear drive wheels remained part of the EV3/Technic drive system.

<p align="center">
  Cheese v4 SPIKE front wheel assemblies
</p>

<p align="center">
  <em>
    Current SPIKE front-wheel configuration used with the Ackermann steering system.
  </em>
</p>

### Why only the front?

The front wheels determine the direction commanded by the Ackermann steering mechanism.

The rear wheels provide propulsion.

Changing only the front therefore allowed us to modify the steering contact without unnecessarily redesigning the rear drive system.

### Expected advantages

- improved front contact,
- cleaner steering response,
- reduced unwanted sliding during turns,
- and better compatibility with the current steering geometry.

### Trade-off

Different front-wheel behavior changes how the robot physically responds to steering commands.

This required real-track testing.

### Systems-thinking connection

<p align="center">
  <strong>
    Front Wheel Contact → Physical Steering Response → Curve Shape → PID Recovery
  </strong>
</p>

---

# ❀ 4.1.12 Decision 08 — Shorten Only the Nano USB Cable ────୨ৎ────────୨ৎ────

It is important to document this decision accurately.

We did **not** replace or shorten every EV3 cable.

The main cable changed was the USB connection between the Arduino Nano and the EV3.

<p align="center">
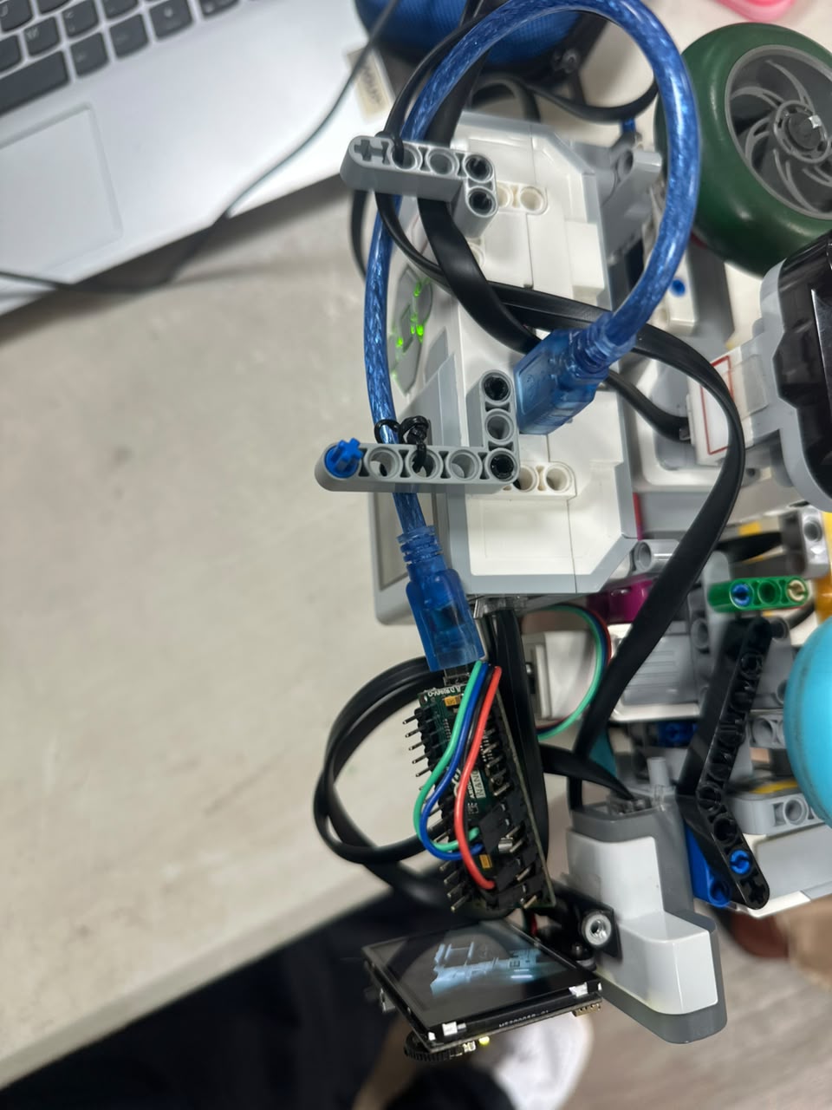
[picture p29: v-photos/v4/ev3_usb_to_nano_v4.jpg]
Cheese v4 EV3 USB to Arduino Nano connection
  
</p>

### Problem

The previous longer USB cable created unnecessary clutter around the Nano and vision-system area.

### Decision

Use a shorter USB Type-A to Mini-B connection for the Arduino Nano.

<div align="center">

| Cable | v4 Decision |
| :--- | :--- |
| **Nano USB** | Shorter cable |
| **EV3 motor cables** | Retained |
| **EV3 sensor cables** | Retained |

</div>

### Result

The communication architecture remained the same:

<p align="center">
  <strong>
    HuskyLens → I²C → Arduino Nano → USB Serial → EV3
  </strong>
</p>

but the physical wiring became easier to manage.

<p align="center">
  Cheese v4 wiring overview
</p>

This demonstrates another important principle:

<p align="center">
  <strong>
    Improve the part creating the problem instead of redesigning everything around it.
  </strong>
</p>

---

# ❀ 4.1.13 Decision 09 — Keep the Arduino Nano Flexible ────୨ৎ────────୨ৎ────

The Arduino Nano serves as the communication bridge between the HuskyLens and EV3.

However, v4 does not use a large permanent LEGO mounting structure dedicated only to holding the Nano.

<p align="center">
  Current Arduino Nano position on Cheese v4
</p>

The Nano is positioned so that:

- it remains connected,
- its cable does not interfere with moving parts,
- it can be inspected,
- and it does not require another heavy structural tower.

### Trade-off

A less rigidly mounted electronic component requires careful cable positioning.

### Why we accepted it

The Nano is lightweight and does not need the same structural support as a motor, EV3 Brick, or steering assembly.

Adding a large dedicated mount would recreate the same structural complexity that v4 was designed to remove.

---

# ❀ 4.1.14 Decision 10 — Prioritize Accessibility and Inspection ────୨ৎ────────୨ৎ────

Competition robots are repeatedly:

- programmed,
- tested,
- charged,
- repaired,
- recalibrated,
- and inspected.

A component that is impossible to reach creates unnecessary testing time.

The v4 architecture therefore considers access as an engineering requirement.

<p align="center">
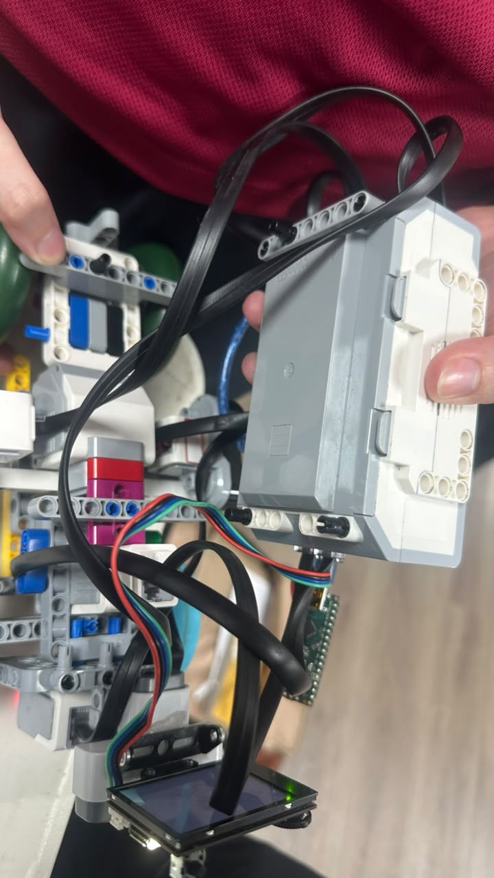
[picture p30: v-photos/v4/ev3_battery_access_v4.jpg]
Cheese v4 EV3 battery access
  
</p>

<p align="center">
  <em>
    Battery accessibility was preserved so the robot can be prepared efficiently between tests.
  </em>
</p>

Accessibility affects reliability because:

<p align="center">
  <strong>
    Easier Inspection → Faster Diagnosis → Faster Repair → More Testing Time
  </strong>
</p>

This does not directly make Cheese drive faster.

It makes the engineering process around Cheese more effective.

---

# ❀ 4.1.15 Major Trade-Off Analysis ────୨ৎ────────୨ৎ────

Every major v4 decision involved a compromise.

<div align="center">

| Decision | Benefit | Risk / Trade-Off | Why Accepted |
| :--- | :--- | :--- | :--- |
| **Reduce mass** | Less unnecessary load | Too much removal could weaken chassis | Essential supports were retained |
| **Lower EV3** | More compact mass distribution | Less unused internal space | Compactness was more valuable |
| **Simplify camera mount** | Less upper structure | Camera angle becomes critical | Large mount was unnecessary |
| **Remove auxiliary lights** | Less mass and complexity | Greater dependence on ambient conditions | Current layout no longer justified them |
| **Lower ultrasonics** | Better wall geometry | Greater physical exposure | Reliable wall readings are essential |
| **Lower color-sensor gap** | Better floor detection | Too low could contact mat | Height was adjusted through testing |
| **Remove sensor cover** | No dragging structure | Less physical light shielding | Current sensor position performs sufficiently |
| **SPIKE front wheels** | Improved steering contact | Different physical response | Front steering behavior benefited |
| **Shorter Nano USB** | Less clutter | Cable must still reach safely | Same architecture with cleaner wiring |
| **Flexible Nano placement** | Less dedicated structure | Requires careful cable management | Nano does not require heavy support |

</div>

This table represents the core of the v4 redesign:

<p align="center">
  <strong>
    No decision was completely free.
    Each improvement was accepted because its benefit was more valuable than its remaining risk.
  </strong>
</p>

---

# ❀ 4.1.16 Failure → Decision → Result Log ────୨ৎ────────୨ৎ────

The strongest design decisions came from failures or limitations observed during testing.

<div align="center">

| Observation / Failure | Engineering Cause | Decision | Result / Learning |
| :--- | :--- | :--- | :--- |
| **Robot accumulated unnecessary structure** | Old solutions remained after design changed | Remove nonessential parts | v4 mass reduced to 666 g |
| **Upper structure became complex** | Camera and lighting supports accumulated | Simplify front/top structure | Cleaner and lower architecture |
| **Wall data limited control quality** | Sensor geometry affects measurements | Improve ultrasonic placement | Better physical conditions for PID |
| **Color detection affected by ambient light** | Floor sensing is sensitive to environment | Tested physical cover | Light was blocked, but cover created drag |
| **Cover dragged on mat** | Mechanical fix introduced new failure | Remove cover and lower sensor slightly | Simpler current color architecture |
| **Vision structure added mass** | Camera function and camera support were treated together | Keep camera, reduce support | Vision retained with less structure |
| **Long Nano cable created clutter** | Excess cable near electronics | Shorten only Nano USB | Cleaner wiring |
| **Steering contact needed improvement** | Front-wheel behavior affects turns | Use SPIKE front wheels | New steering contact tested |
| **Battery condition changed behavior** | Motors respond physically to available power | Consider battery during calibration | Avoid unnecessary software retuning |

</div>

This process can be summarized as:

<p align="center">
  <strong>
    Failure → Identify Cause → Change the Correct Subsystem → Test Again
  </strong>
</p>

---

# ❀ 4.1.17 Risk Identification and Mitigation ────୨ৎ────────୨ৎ────

A design can improve while still containing risks.

Recognizing those risks is part of engineering.

<div align="center">

| Current Risk | System Effect | Mitigation |
| :--- | :--- | :--- |
| **Structure becomes too flexible** | Sensor or steering alignment can change | Retain essential structural supports |
| **Ultrasonic reading fluctuates** | PID may request incorrect correction | Physical placement + software filtering |
| **Color line is missed** | Curve count can become incorrect | Improved floor gap + software validation |
| **Camera sees pillar too late** | Avoidance time decreases | Continue HuskyLens angle/timing calibration |
| **Obstacle avoidance is weak** | Cheese may contact/carry pillar | Continue avoidance-strength tuning |
| **Poor post-obstacle recovery** | Next pillar may enter view from bad heading | Recovery remains current obstacle priority |
| **Parking count is wrong** | Parking activates early or late | Validate curve-count logic |
| **Battery becomes weak** | Motor response changes | Test with appropriate battery condition |
| **Cable interferes with mechanism** | Mechanical or communication failure | Keep wiring short, visible and secured |

</div>

Risk mitigation does not mean that every risk has disappeared.

It means the team knows **what can fail, why it matters, and what is being done about it**.

---

# ❀ 4.1.18 Decisions We Intentionally Did NOT Make ────୨ৎ────────୨ৎ────

An engineering log should also explain changes that were avoided.

<div align="center">

| Possible Change | Why We Did Not Do It |
| :--- | :--- |
| **Replace every cable** | Only the Nano USB was creating significant clutter |
| **Remove every structural support** | Low weight is useless if the chassis becomes flexible |
| **Redesign the rear wheels** | The front steering contact was the area being changed |
| **Add the auxiliary lights back** | Current v4 architecture does not require them for normal operation |
| **Create a large Nano mount** | It would add structure without enough functional benefit |
| **Move the color sensor to a completely new location** | Its general floor-facing placement already worked |
| **Solve poor sensor data only through software** | Physical sensor geometry should be corrected first |

</div>

This was an important change in our engineering process.

<p align="center">
  <strong>
    Not changing something can also be a design decision.
  </strong>
</p>

---

# ❀ 4.1.19 Current System Status After the v4 Decisions ────୨ৎ────────୨ৎ────

The v4 redesign improved Cheese, but not every subsystem reached the same development stage at the same time.

<div align="center">

| System | Current Status | Engineering Note |
| :--- | :--- | :--- |
| **v4 mechanical structure** | 🟢 Improved | Lighter, lower and easier to inspect |
| **Open navigation** | 🟢 Mostly reliable | Three-lap runs are functioning |
| **Open curve counting** | 🟢 Functional | Still important to overall parking reliability |
| **Open PID / wall protection** | 🟢 Functional | Continues to be tuned for repeatability |
| **Front recovery** | 🟢 Functional | Creates space when forward clearance becomes unsafe |
| **Open parking** | 🟢 Functional | Usually stops inside the region |
| **Final parking angle** | 🟡 Tunable | Can still finish slightly angled |
| **HuskyLens color recognition** | 🟢 Functional | Green = ID 1, Red = ID 2 |
| **Obstacle avoidance** | 🟡 In calibration | Detection works, physical maneuver still needs consistency |
| **Post-obstacle recovery** | 🟡 Main tuning challenge | Exit position affects the next detection |
| **Obstacle parking** | 🟡 Pending / in progress | Depends on stable obstacle navigation first |
| **Battery consistency** | 🟡 Testing variable | Can affect motor response |

</div>

This status is documented intentionally.

<p align="center">
  <strong>
    v4 is an improvement supported by testing — not a claim that every remaining problem has disappeared.
  </strong>
</p>

---

# ❀ 4.1.20 V4 Decision Priority Map ────୨ৎ────────୨ৎ────

The decisions made during the redesign can be grouped by their main purpose.

<div align="center">

| Priority | Decisions |
| :--- | :--- |
| ⚖️ **Reduce unnecessary mass** | Remove excess structure, remove lighting supports, simplify camera structure |
| 📡 **Improve sensor information** | Lower ultrasonics, optimize color-sensor floor gap, calibrate camera angle |
| 🛞 **Improve physical motion** | SPIKE front wheels, compact structure, Ackermann integration |
| 🔌 **Improve accessibility** | Shorter Nano USB, cleaner wiring, accessible EV3/battery |
| 💻 **Support software reliability** | Better physical sensor inputs before increasing software correction |
| 🧪 **Improve testing efficiency** | Fewer unnecessary parts, easier inspection and faster diagnosis |

</div>

The priorities are connected.

For example:

<p align="center">
  <strong>
    Less Structure → Lower Mass → Easier Motion → Cleaner Sensor Response → Easier Calibration
  </strong>
</p>

and:

<p align="center">
  <strong>
    Better Sensor Placement → Better Data → Better Software Decisions → Better Physical Navigation
  </strong>
</p>

---

# ❀ 4.1.21 Final Design Decision Summary ────୨ৎ────────୨ৎ────

Cheese v4 was developed by simplifying the robot around the systems that matter most.

<div align="center">

| v4 Decision | Main Engineering Purpose |
| :--- | :--- |
| **Reduce 888.8 g to 666 g** | Remove unnecessary load and simplify calibration |
| **Lower and compact the chassis** | Improve layout and accessibility |
| **Lower the EV3 Brick** | Reduce upper structure and improve access |
| **Simplify HuskyLens support** | Preserve vision with less structure |
| **Remove auxiliary lighting** | Eliminate hardware no longer justified by current layout |
| **Use three ultrasonic sensors** | Improve lateral and forward awareness |
| **Improve ultrasonic placement** | Improve the data entering navigation control |
| **Keep color sensor in same general area** | Preserve a proven sensing architecture |
| **Adjust color-sensor floor gap** | Improve detection without a dragging cover |
| **Use SPIKE front wheels** | Improve steering contact |
| **Shorten only Nano USB** | Reduce clutter without unnecessary rewiring |
| **Keep Nano mounting lightweight** | Avoid rebuilding unnecessary structural complexity |
| **Preserve battery access** | Make repeated testing easier |
| **Continue obstacle calibration honestly** | Do not claim reliability before testing proves it |

</div>

The strongest lesson from the v3 → v4 redesign was not that lighter is always better or that fewer parts are always better.

It was this:

<p align="center">
  <strong>
    Every component should justify the complexity it adds to the complete system.
  </strong>
</p>

Cheese v4 became lighter, cleaner and easier to calibrate because the team began evaluating components according to their **function and system effect**, rather than simply keeping every solution introduced during earlier prototypes.

The resulting engineering philosophy is:

<p align="center">
  <strong>
    Observe → Understand → Simplify → Test → Keep What Works
  </strong>
</p>

<p align="center">
  ✦ ─── ⋆⋅☆⋅⋆ ─── 🧀 Engineering Decision Vault 🧀 ─── ⋆⋅☆⋅⋆ ─── ✦
</p>

<p align="center">
  <a href="https://github.com/Quesovamos2662/WRO2026_FE_Go-Cheese#general-project-index">
    
  </a>
</p>

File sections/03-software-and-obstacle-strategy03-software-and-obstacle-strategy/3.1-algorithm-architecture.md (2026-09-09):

<h1 align="center">ᯓ★ 3.1 Algorithm Architecture ᯓ★</h1>

<p align="center">
  
  
  
  
</p>

<p align="center">
  <em>
    This section explains how Cheese v4 organizes sensing, validation,
    navigation, safety, curve tracking, vision, obstacle response,
    recovery, and parking into one structured control architecture.
  </em>
</p>

<p align="center">
  ✦ ─── ⋆⋅☆⋅⋆ ─── 🧀🤖 ─── ⋆⋅☆⋅⋆ ─── ✦
</p>

---

Cheese v4 is built around a **priority-based, minimum-correction architecture**.

The robot does not attempt to correct every small difference detected by its sensors.

Instead, the software asks:

```text
IS A CORRECTION ACTUALLY NEEDED?
```

If not:

```text
DRIVE WITH MINIMAL STEERING
```

If correction is needed:

```text
IDENTIFY WHY
      ↓
APPLY THE APPROPRIATE CONTROL
```

This reduces unnecessary steering and helps prevent several control systems from fighting each other.

The general architecture is:

```text
SENSE
  ↓
VALIDATE
  ↓
REMEMBER STATE
  ↓
INTERPRET
  ↓
PRIORITIZE
  ↓
CONTROL
  ↓
MOVE
  ↓
RECOVER
  ↓
REPEAT
```

---

# ❀ 3.1.1 Current Software Files ────୨ৎ────────୨ৎ────

Cheese currently uses separate programs for the two Future Engineers rounds.

<div align="center">

| Challenge | Current Main File | Main Purpose | Status |
| :--- | :--- | :--- | :--- |
| **Open Challenge** | `GOOD_CURVE_COUNTER_TEST11_PROGRESSIVE_ESCAPE_REVERSE_RETRACE.py` | Navigation, curve counting, wall safety, front recovery, three laps and parking | 🟢 Near-final calibration |
| **Obstacle Challenge** | `GOODYIPEE (1)(3) (21).py` | Navigation plus camera detection, pillar avoidance and recovery | 🟡 Active calibration |

</div>

The two programs remain separate because the Obstacle Challenge introduces additional experimental behaviors that should not destabilize the more mature Open system.

```text
OPEN
 ↓
NAVIGATION
CURVE COUNT
SAFETY
PARKING
```

while:

```text
OBSTACLE
 ↓
NAVIGATION
   +
VISION
   +
PILLAR RESPONSE
   +
RECOVERY
```

---

# ❀ 3.1.2 Architecture Goal ────୨ৎ────────୨ৎ────

The main architecture goal is to allow several behaviors to cooperate without producing contradictory motor commands.

<div align="center">

| Behavior | Why It Needs Control |
| :--- | :--- |
| **Normal driving** | Cheese must continue moving when no correction is needed |
| **Wall correction** | Prevent side-wall contact |
| **Front safety** | Prevent direct front-wall collisions |
| **Curve tracking** | Know how much of the course is complete |
| **Parking** | Finish after the correct progress |
| **Obstacle detection** | Detect red and green pillars |
| **Obstacle avoidance** | Pass each pillar on the required side |
| **Recovery** | Return to a useful trajectory afterward |

</div>

Without an architecture, these behaviors could all request steering at the same time.

The purpose of the control system is therefore not only to calculate an angle.

It must decide **which behavior should matter most at that moment**.

---

# ❀ 3.1.3 Software Architecture Overview ────୨ৎ────────୨ৎ────

<p align="center">
  Cheese v4 software flowchart set map
</p>

<p align="center">
  <em>
    Map of the main Cheese v4 software subsystems documented throughout Section 3.
  </em>
</p>

The architecture can be divided into:

```text
INPUT
 ↓
VALIDATION
 ↓
STATE
 ↓
DECISION
 ↓
CONTROL
 ↓
OUTPUT
```

More specifically:

<div align="center">

| Layer | Function |
| :--- | :--- |
| **Input layer** | Read sensors and camera data |
| **Validation layer** | Remove unreliable information |
| **State layer** | Remember previous events |
| **Decision layer** | Determine current situation |
| **Priority layer** | Decide which behavior has authority |
| **Control layer** | Calculate steering and speed |
| **Output layer** | Command drive and steering motors |

</div>

---

# ❀ 3.1.4 Hardware Map Used by the Algorithm ────୨ৎ────────୨ৎ────

The software architecture depends on the physical hardware map matching the code.

<p align="center">
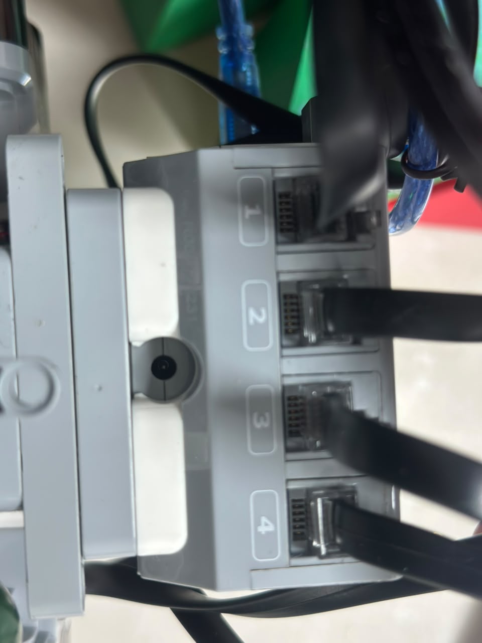
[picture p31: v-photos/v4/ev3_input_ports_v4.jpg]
Cheese v4 EV3 input ports
  
  &nbsp;
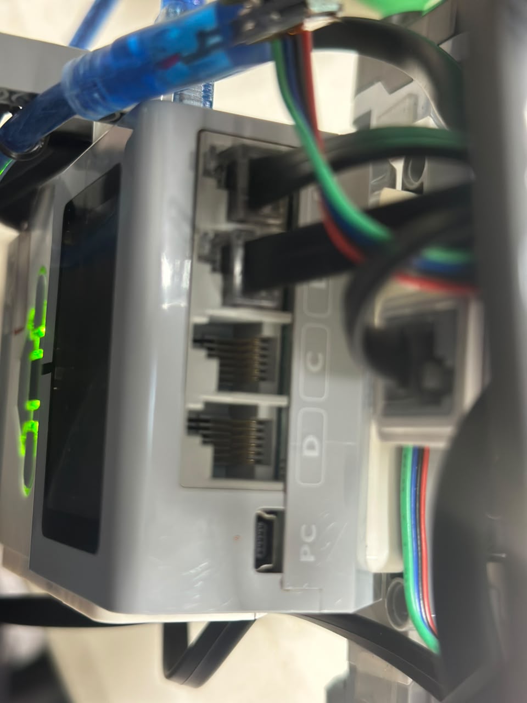
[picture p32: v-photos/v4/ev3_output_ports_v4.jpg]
Cheese v4 EV3 output ports
  
</p>

<p align="center">
  <em>
    Current EV3 input and output connections used by Cheese v4.
  </em>
</p>

<div align="center">

| Component | Port / Connection | Algorithm Role |
| :--- | :---: | :--- |
| **Medium Motor** | `OUTPUT_A` | Ackermann steering |
| **Large Motor** | `OUTPUT_B` | Rear-wheel propulsion |
| **Left Ultrasonic** | `INPUT_1` | Left wall distance |
| **Right Ultrasonic** | `INPUT_2` | Right wall distance |
| **Front Ultrasonic** | `INPUT_3` | Forward-distance safety |
| **EV3 Color Sensor** | `INPUT_4` | Floor-color / curve tracking |
| **Arduino Nano** | EV3 USB | Vision communication bridge |
| **HuskyLens** | Nano via I²C | Obstacle detection |

</div>

The detailed physical connections are documented in **Section 2.2 Wiring Diagram**.

---

# ❀ 3.1.5 Program Structure ────୨ৎ────────୨ৎ────

The current Cheese code follows a modular structure.

<div align="center">

| Program Block | Purpose |
| :--- | :--- |
| **Imports** | Load EV3 motor, sensor, timing and communication tools |
| **Hardware setup** | Assign sensors and motors |
| **Constants** | Store tuning values |
| **State variables** | Remember information between cycles |
| **Sensor functions** | Read hardware |
| **Validation functions** | Reject unreliable values |
| **Steering functions** | Control steering movement |
| **PID functions** | Calculate navigation correction |
| **Curve functions** | Detect track progress |
| **Safety functions** | Handle dangerous front distance |
| **Vision functions** | Receive and interpret obstacle data |
| **Parking functions** | Detect final position |
| **Main loop** | Coordinate all subsystems |
| **Shutdown logic** | Stop motors safely |

</div>

This structure makes failures easier to isolate.

Instead of asking:

```text
WHY DID THE WHOLE ROBOT FAIL?
```

the team can ask:

```text
WAS IT:
SENSING?
VALIDATION?
PID?
CURVE COUNT?
VISION?
RECOVERY?
PARKING?
```

---

# ❀ 3.1.6 Main Control Loop ────୨ৎ────────୨ৎ────

<p align="center">
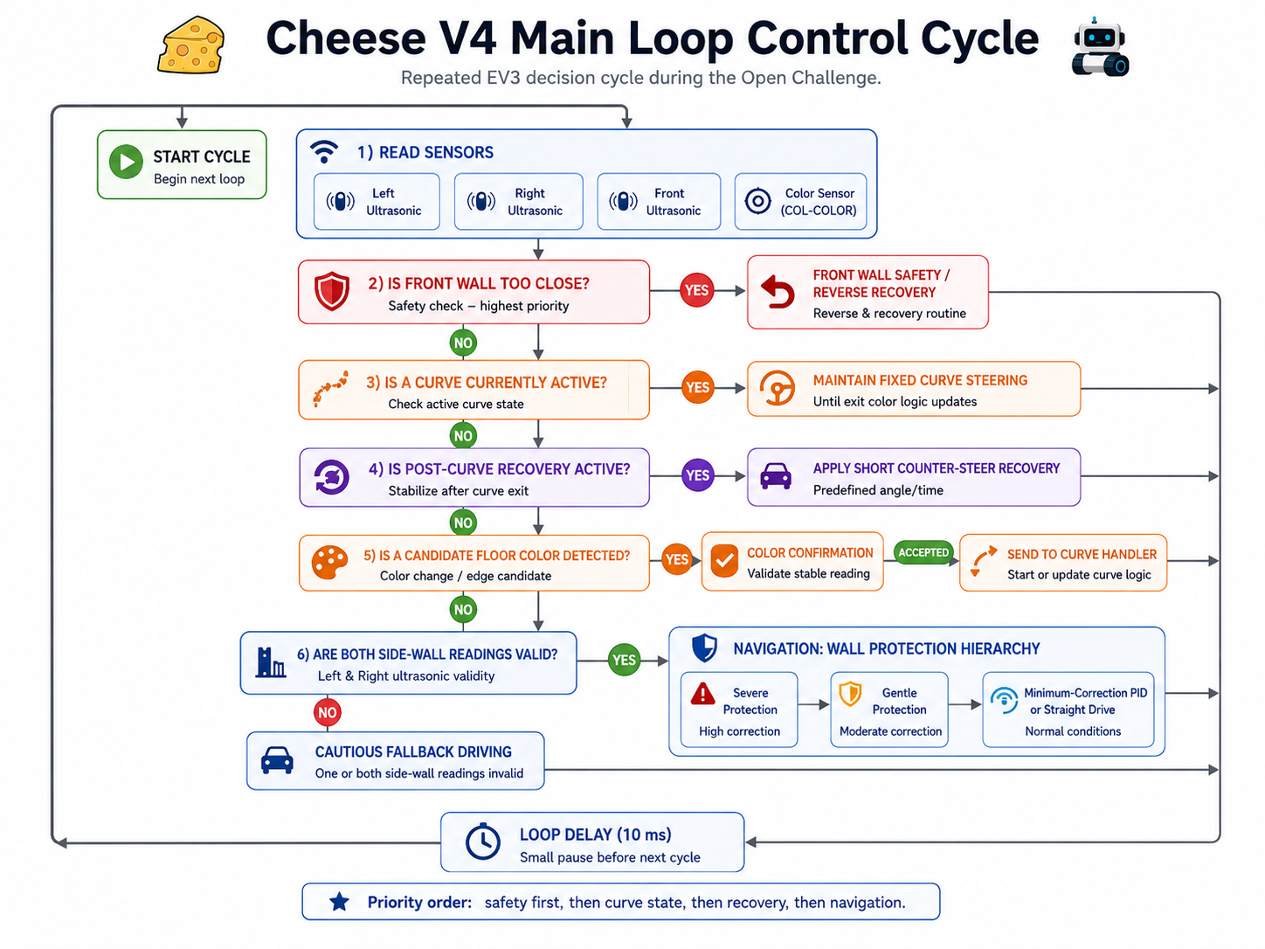
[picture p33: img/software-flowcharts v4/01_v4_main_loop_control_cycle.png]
Cheese v4 main control loop
  
</p>

<p align="center">
  <em>
    Repeated control cycle used during autonomous navigation.
  </em>
</p>

A simplified cycle is:

```text
LOOP START
    ↓
CHECK STOP CONDITION
    ↓
READ FRONT SENSOR
    ↓
RUN SAFETY IF REQUIRED
    ↓
READ FLOOR COLOR
    ↓
UPDATE CURVE STATE
    ↓
READ SIDE SENSORS
    ↓
VALIDATE / FILTER
    ↓
CALCULATE NAVIGATION
    ↓
READ CAMERA DATA
(Obstacle mode)
    ↓
APPLY ALLOWED CAMERA INFLUENCE
    ↓
COMMAND MOTORS
    ↓
CHECK FINISH
    ↓
REPEAT
```

The Open loop uses an approximately:

```text
0.01 s
```

delay between iterations.

---

# ❀ 3.1.7 Priority-Based Control ────୨ৎ────────୨ৎ────

Cheese does not treat every behavior equally.

A simplified control hierarchy is:

```text
SAFETY
  ↓
WALL PROTECTION
  ↓
TRACK / NAVIGATION LOGIC
  ↓
VISION RESPONSE
  ↓
NORMAL MOVEMENT
```

Parking becomes dominant when the run-completion condition is reached.

<div align="center">

| Control Layer | Main Trigger | Response |
| :--- | :--- | :--- |
| **Front safety** | Dangerous front distance | Create space / recover |
| **Wall protection** | Dangerous lateral distance | Protective steering |
| **Curve progress** | Valid color transition | Update progress |
| **PID navigation** | Useful navigation error | Correct trajectory |
| **Vision response** | Valid fresh pillar detection | Add obstacle steering influence |
| **Normal movement** | No important correction | Minimal steering |
| **Parking** | Required progress complete | Finish sequence |

</div>

The main architectural principle is:

<p align="center">
  <strong>
    Higher-risk situations should prevent lower-priority commands from creating a worse situation.
  </strong>
</p>

---

# ❀ 3.1.8 Sensor Validation Architecture ────୨ৎ────────୨ৎ────

<p align="center">
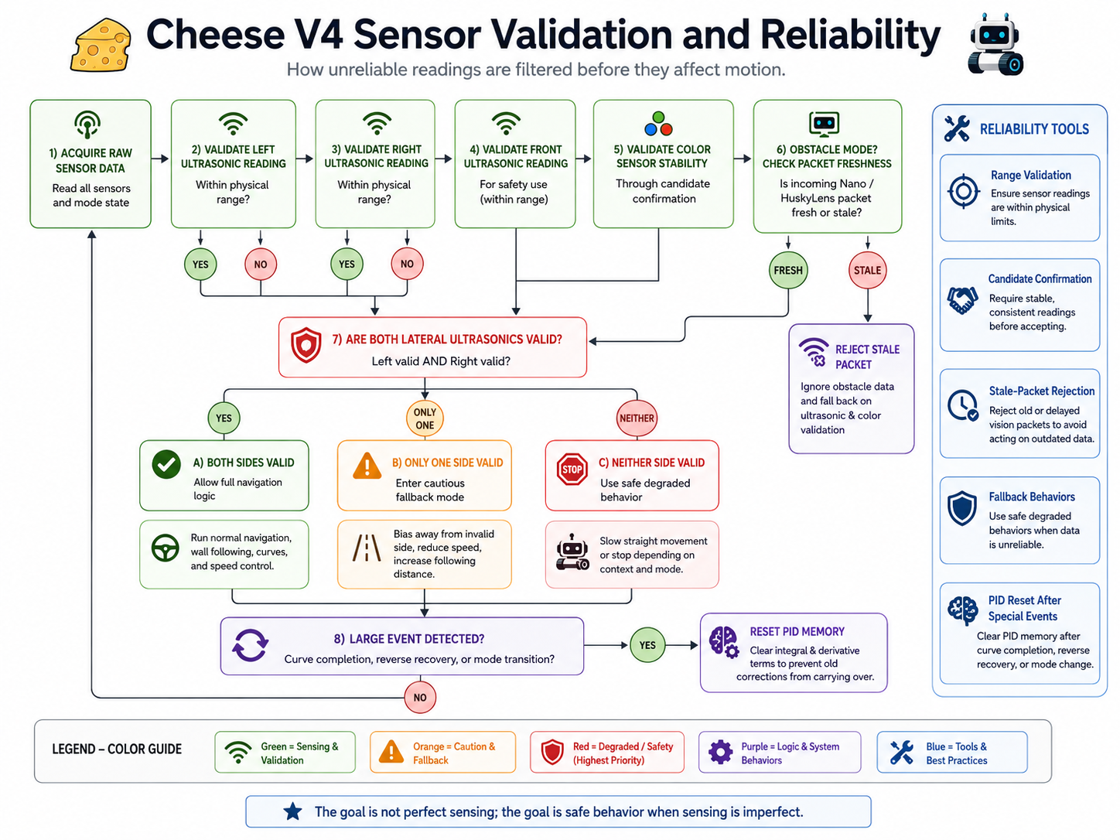
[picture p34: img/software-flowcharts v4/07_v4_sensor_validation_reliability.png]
Cheese v4 sensor validation architecture
  
</p>

Sensor information is processed before it controls movement.

```text
RAW VALUE
   ↓
VALID?
 ↓   ↓
NO   YES
│     │
IGNORE FILTER
       ↓
    INTERPRET
       ↓
      USE
```

Current reliability mechanisms include:

- ultrasonic distance validation,
- ultrasonic filtering,
- derivative filtering,
- color-sequence validation,
- curve cooldown,
- steering confirmation,
- front-distance confirmations,
- camera freshness checks,
- lost-pillar reset,
- and control-state resets.

---

# ❀ 3.1.9 State and Memory ────୨ৎ────────୨ৎ────

Cheese needs memory because one sensor reading only describes one instant.

State variables connect different moments of the run.

### Navigation State

<div align="center">

| State | Purpose |
| :--- | :--- |
| PID integral | Stores limited accumulated error |
| Previous error | Supports derivative calculation |
| Filtered derivative | Reduces sharp steering changes |
| Filtered sensor values | Smooth distance measurements |

</div>

### Curve State

<div align="center">

| State | Purpose |
| :--- | :--- |
| First color | Beginning of possible curve sequence |
| First-color time | Sequence timeout |
| Completed curves | Overall progress |
| Previous count time | Cooldown |
| Steering confirmation | Validate physical turning |
| Pending second color | Wait for final validation |

</div>

### Parking State

<div align="center">

| State | Purpose |
| :--- | :--- |
| Starting left distance | Initial side reference |
| Starting right distance | Initial side reference |
| Starting front distance | Main final reference |
| Finish confirmations | Prevent noisy final stop |
| Previous finish measurement | Detect target crossing |

</div>

### Vision State

<div align="center">

| State | Purpose |
| :--- | :--- |
| Current pillar color | Green / red / none |
| xCenter | Horizontal camera position |
| Width | Apparent pillar size |
| Last update time | Determine freshness |
| Camera bias | Current obstacle steering influence |
| Lost-pillar state | Clear old obstacle commands |

</div>

---

# ❀ 3.1.10 Minimum-Correction PID ────୨ৎ────────୨ৎ────

<p align="center">
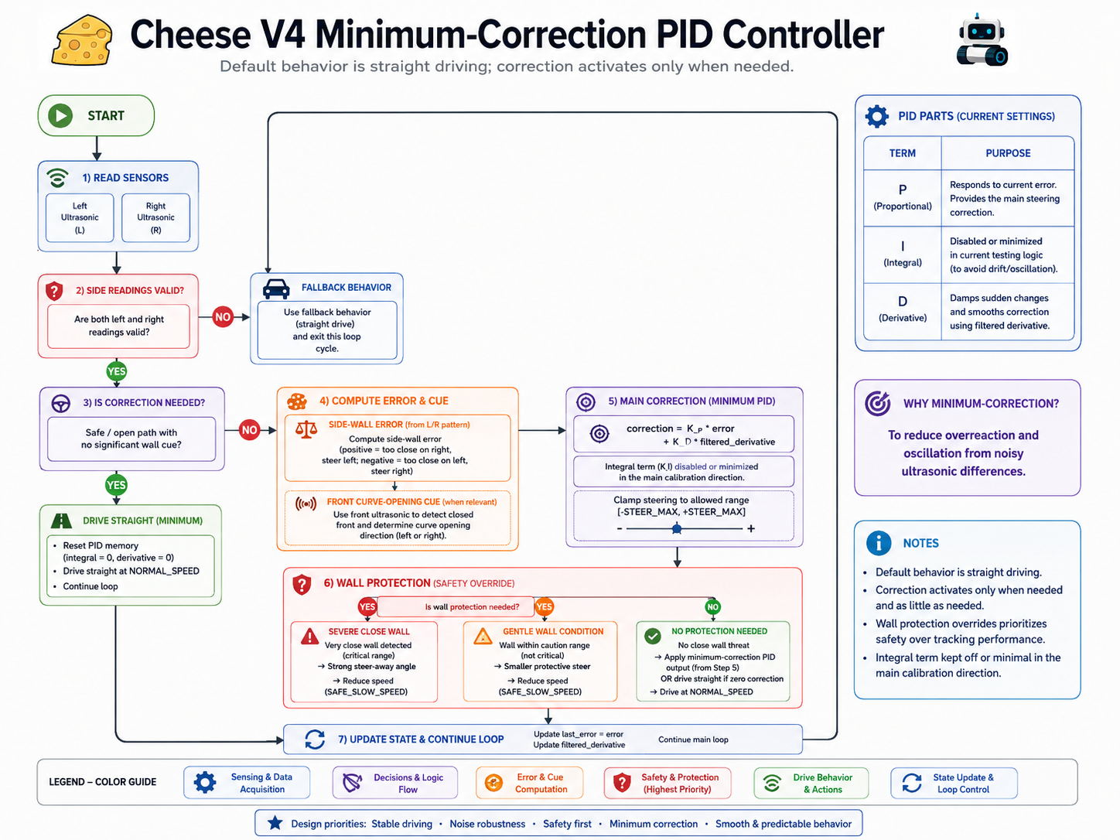
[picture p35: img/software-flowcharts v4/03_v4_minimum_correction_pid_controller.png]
Cheese v4 minimum correction PID
  
</p>

The controller does not continuously try to center Cheese perfectly.

Instead:

```text
SAFE
 ↓
STRAIGHT

USEFUL ERROR
 ↓
PID

GREATER DANGER
 ↓
STRONGER PROTECTION
```

Current Open PID values include:

<div align="center">

| Constant | Current Value |
| :--- | :---: |
| `KP` | `0.28` |
| `KI` | `0.001` |
| `KD` | `0.08` |
| Integral limit | `20` |
| Center deadband | `1.5` |
| Maximum PID angle | `32°` |

</div>

The goal is not mathematical perfection.

The goal is **stable physical movement**.

---

# ❀ 3.1.11 Why Minimum Correction Was Chosen ────୨ৎ────────୨ৎ────

Earlier aggressive correction can produce:

```text
SMALL ERROR
   ↓
STEER
   ↓
CROSS TARGET
   ↓
STEER BACK
   ↓
CROSS AGAIN
   ↓
ZIG-ZAG
```

The current philosophy instead aims for:

```text
SAFE
 ↓
STRAIGHT

DRIFT
 ↓
CORRECT

SAFE AGAIN
 ↓
STRAIGHT
```

This reduces steering oscillation.

---

# ❀ 3.1.12 Progressive Wall Protection ────୨ৎ────────୨ৎ────

The Open controller uses progressively stronger wall protection.

<div align="center">

| Parameter | Current Value |
| :--- | :---: |
| Gentle wall distance | `28.0 cm` |
| Severe wall distance | `22.0 cm` |
| Full wall avoidance | `15.0 cm` |
| Gentle wall angle | `14°` |
| Severe wall angle | `18°` |

</div>

The architecture becomes:

```text
SAFE
 ↓
NORMAL NAVIGATION

CLOSER
 ↓
GENTLE RESPONSE

DANGEROUS
 ↓
SEVERE RESPONSE

CRITICAL
 ↓
FULL PROTECTION
```

This allows Cheese to respond before physical contact.

---

# ❀ 3.1.13 Steering Command Architecture ────୨ৎ────────୨ৎ────

Steering commands are also limited.

<div align="center">

| Steering Parameter | Current Value |
| :--- | :---: |
| Steering speed | `60` |
| Deadband | `0.8°` |
| Turn step | `3.0°` |
| Return step | `5.0°` |
| Soft steering start | `10°` |
| Full steering authority | `24°` |
| Maximum PID angle | `32°` |

</div>

The command chain is:

```text
REQUEST ANGLE
      ↓
LIMIT
      ↓
COMPARE WITH CURRENT POSITION
      ↓
CONTROLLED STEERING STEP
      ↓
MEDIUM MOTOR
      ↓
ACKERMANN LINKAGE
```

The software therefore respects the physical steering mechanism.

---

# ❀ 3.1.14 Front-Wall Safety Architecture ────୨ৎ────────୨ৎ────

<p align="center">
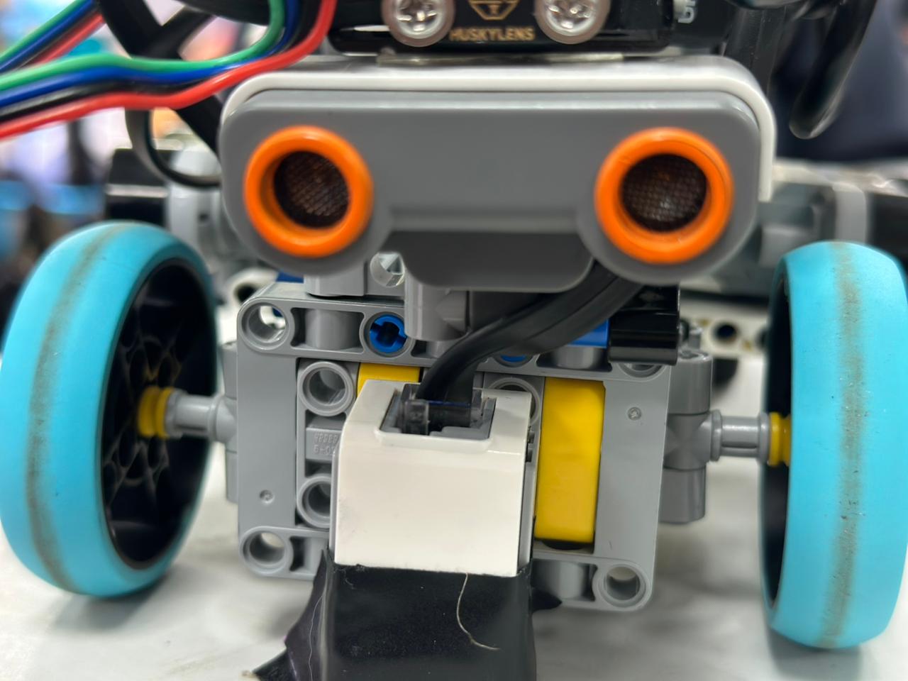
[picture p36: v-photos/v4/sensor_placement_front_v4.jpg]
Cheese v4 front ultrasonic sensor
  
</p>

<p align="center">
  <em>
    Front ultrasonic placement used for forward-distance safety.
  </em>
</p>

<p align="center">
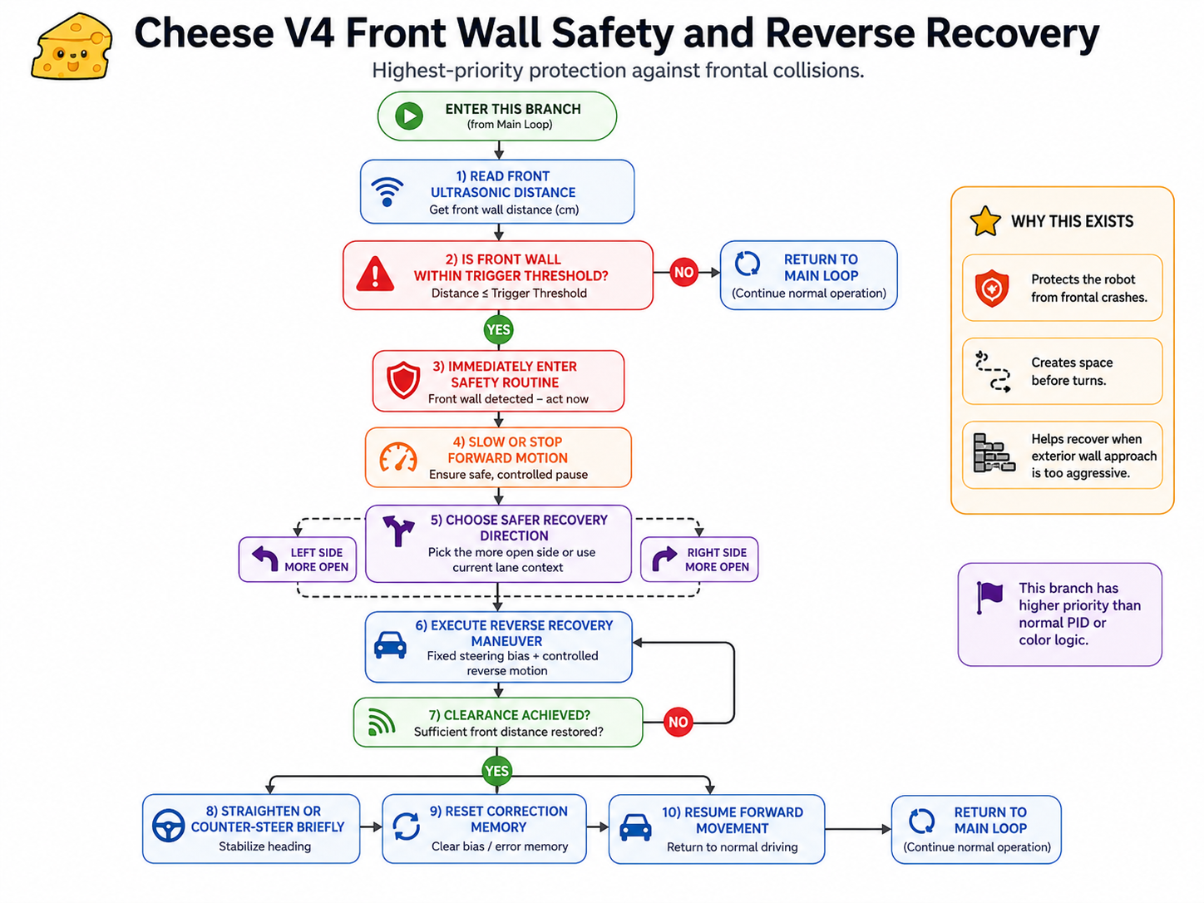
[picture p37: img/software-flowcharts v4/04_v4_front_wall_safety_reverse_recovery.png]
Cheese v4 front wall reverse recovery
  
</p>

The safety branch works conceptually as:

```text
READ FRONT DISTANCE
        ↓
DANGER?
   ┌────┴────┐
  NO        YES
  │          │
CONTINUE   CONFIRM
             ↓
          RECOVER
             ↓
        CREATE SPACE
             ↓
        RETURN TO LOOP
```

Current values include:

<div align="center">

| Parameter | Value |
| :--- | :---: |
| Front assist begins | `70 cm` |
| Maximum front assist | `10°` |
| Too-close threshold | `10 cm` |
| Recovery target | `30 cm` |
| Confirmations | `3` |
| Recovery timeout | `1.8 s` |
| Maximum reverse steering | `10°` |

</div>

---

# ❀ 3.1.15 Curve-Counting Architecture ────୨ৎ────────୨ৎ────

The EV3 Color Sensor provides progress information.

<p align="center">
  Cheese v4 color sensor placement
</p>

<p align="center">
  <em>
    Current floor-facing color sensor position.
  </em>
</p>

The software interprets:

```text
BLUE → BLUE
```

and groups several warm classifications into:

```text
RED
YELLOW
BROWN
   ↓
ORANGE
```

A valid curve sequence is:

```text
BLUE → ORANGE
```

or:

```text
ORANGE → BLUE
```

<p align="center">
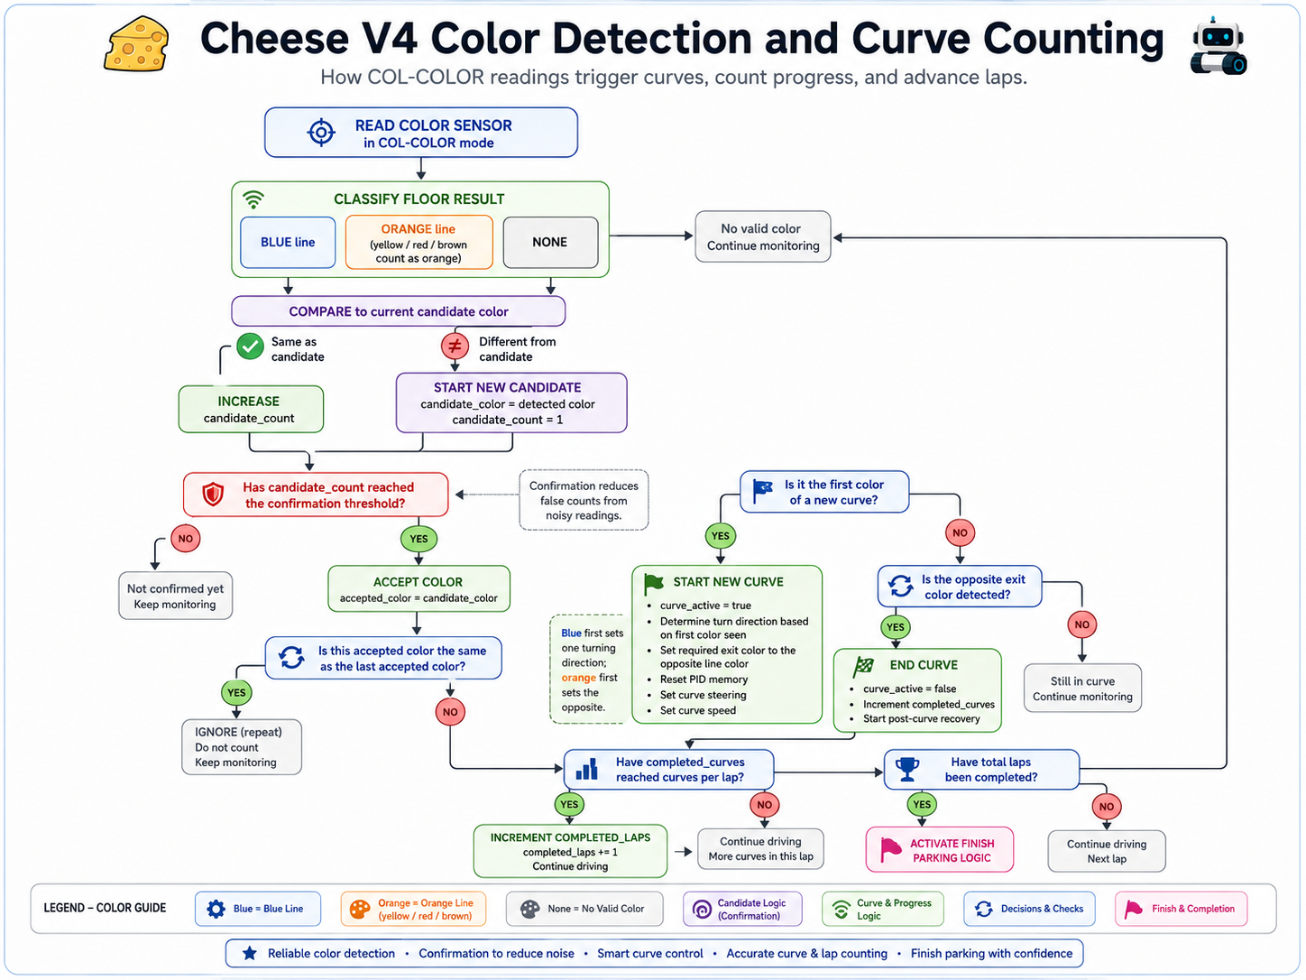
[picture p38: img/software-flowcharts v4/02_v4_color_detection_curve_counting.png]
Cheese v4 curve counting architecture
  
</p>

Current curve-count values include:

<div align="center">

| Parameter | Value |
| :--- | :---: |
| Total curves | `12` |
| Color-change window | `3.0 s` |
| Curve cooldown | `1.5 s` |
| Minimum steering angle | `0.1°` |
| Minimum steering time | `0.03 s` |
| Post-color steering window | `0.9 s` |

</div>

---

# ❀ 3.1.16 Curve Counter as a State Machine ────୨ৎ────────୨ৎ────

The curve counter does not simply count every detected color.

It behaves like a small state machine.

```text
NO FIRST COLOR
      ↓
DETECT BLUE / ORANGE
      ↓
STORE FIRST COLOR
      ↓
WAIT
      ↓
OPPOSITE COLOR?
      ↓
YES
      ↓
VALID TIMING?
      ↓
STEERING CONFIRMATION?
      ↓
COUNT
      ↓
RESET
```

This architecture greatly reduces duplicate or false progress events.

---

# ❀ 3.1.17 Parking Architecture ────୨ৎ────────୨ৎ────

Parking is connected to both run progress and starting-position memory.

<p align="center">
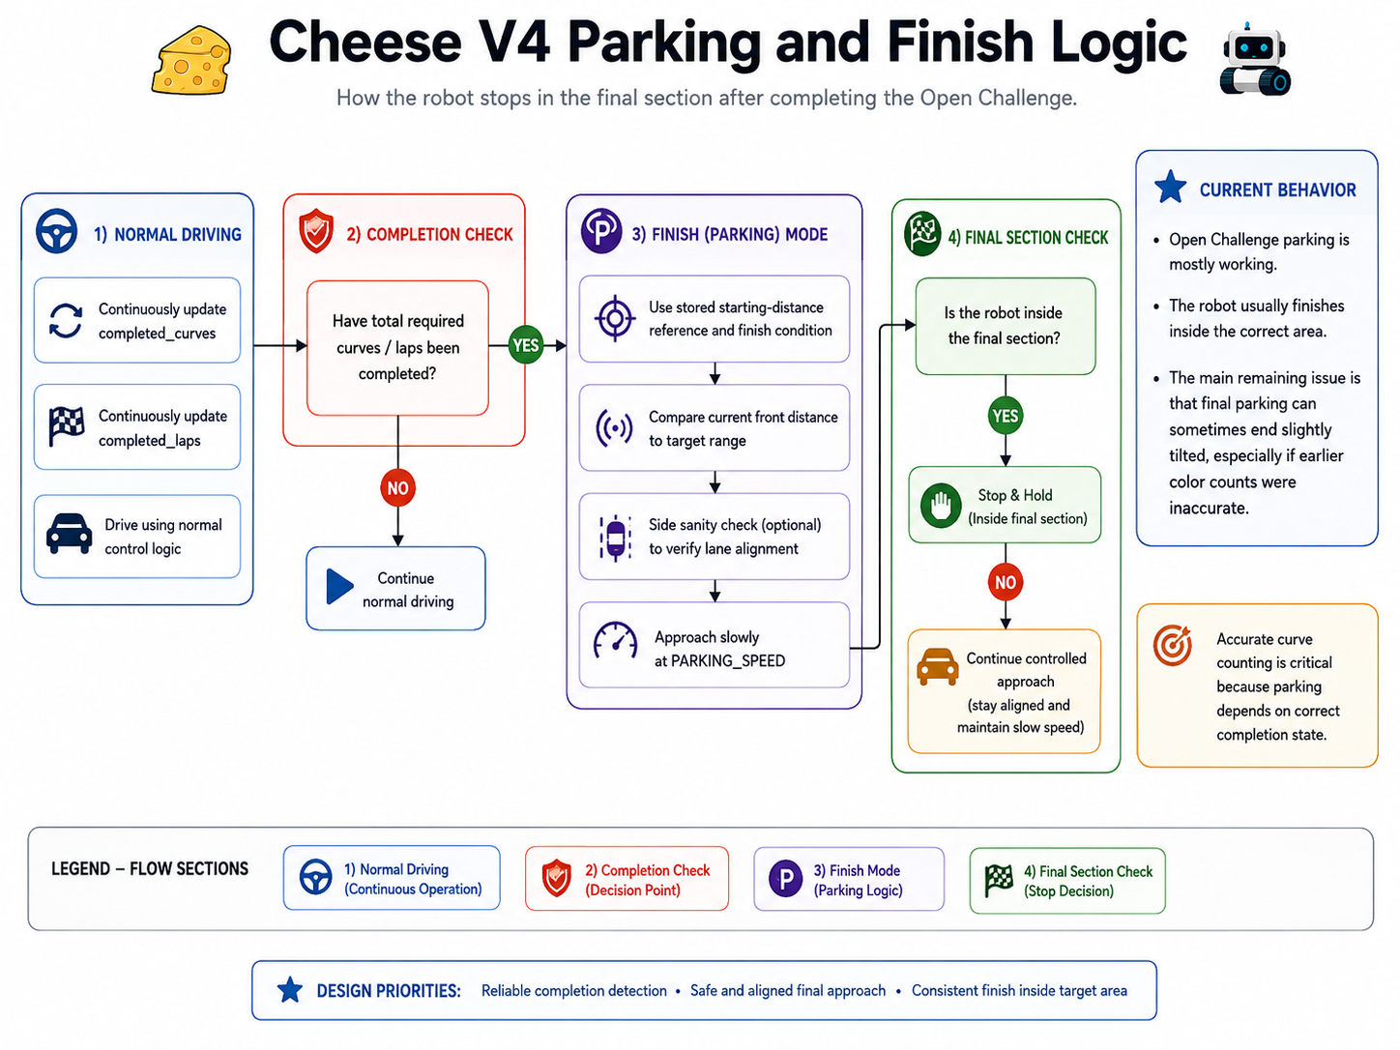
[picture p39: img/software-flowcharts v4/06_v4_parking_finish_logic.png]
Cheese v4 parking architecture
  
</p>

The architecture is:

```text
START
 ↓
SAVE DISTANCE REFERENCES
 ↓
COMPLETE RUN
 ↓
12 CURVES
 ↓
PARKING ENABLED
 ↓
RETURN TOWARD START
 ↓
COMPARE FRONT DISTANCE
 ↓
SLOW
 ↓
STOP
```

Current parking speeds include:

<div align="center">

| Stage | Speed |
| :--- | :---: |
| Parking approach | `-28` |
| Medium approach | `-18` |
| Final creep | `-10` |

</div>

This makes parking part of the same sensor-driven architecture rather than a timed final movement.

---

# ❀ 3.1.18 Obstacle Vision Architecture ────୨ৎ────────୨ৎ────

Obstacle mode adds a vision branch to the normal navigation architecture.

<p align="center">
  Cheese v4 HuskyLens front placement
</p>

The data path is:

```text
HUSKYLENS
    ↓
I²C
    ↓
ARDUINO NANO
    ↓
USB SERIAL
    ↓
EV3
    ↓
CAMERA STEERING LOGIC
```

The camera provides information about:

```text
COLOR
POSITION
SIZE
```

rather than directly commanding the motors.

---

# ❀ 3.1.19 Current Vision Classification Evidence ────୨ৎ────────୨ৎ────

The current HuskyLens configuration has been tested physically with both obstacle colors.

<p align="center">
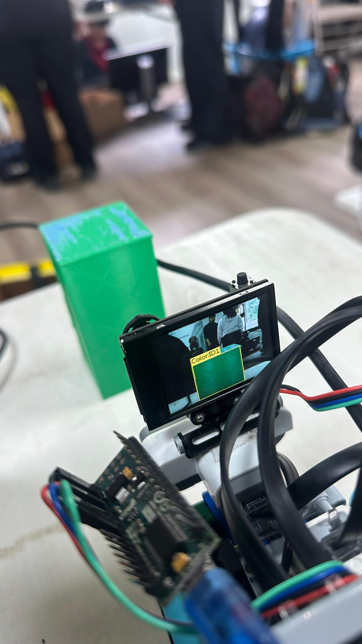
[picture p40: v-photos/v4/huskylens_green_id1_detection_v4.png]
HuskyLens detecting green pillar as Color ID 1
  
  &nbsp;
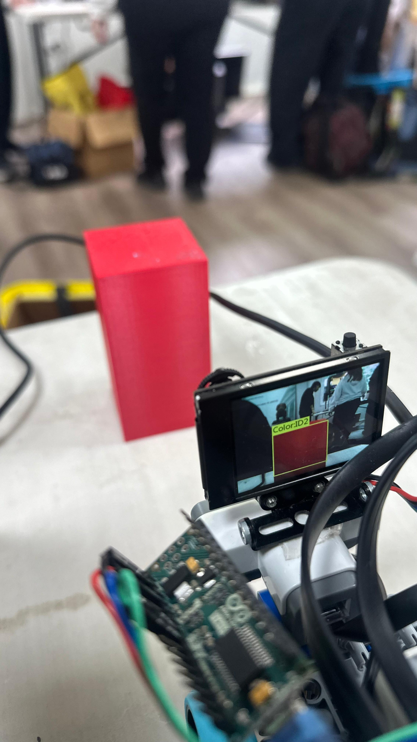
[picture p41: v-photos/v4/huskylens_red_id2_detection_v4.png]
HuskyLens detecting red pillar as Color ID 2
  
</p>

<p align="center">
  <em>
    Current HuskyLens recognition evidence:
    Green = Color ID 1 and Red = Color ID 2.
  </em>
</p>

<div align="center">

| Physical Pillar | Current HuskyLens ID | Required Passing Rule |
| :--- | :---: | :--- |
| 🟢 **Green** | **ID 1** | Pass on the **left** |
| 🔴 **Red** | **ID 2** | Pass on the **right** |

</div>

This is important because the software architecture must match the **actual trained camera configuration**.

The chain is:

```text
HUSKYLENS ID
      ↓
SOFTWARE COLOR
      ↓
PASSING RULE
      ↓
STEERING RESPONSE
```

A mismatch at any step could create the wrong physical behavior.

---

# ❀ 3.1.20 Vision Packet Architecture ────୨ৎ────────୨ৎ────

The Nano sends simplified information to the EV3.

```text
R,xCenter,width
```

for red,

```text
G,xCenter,width
```

for green,

and:

```text
N,0,0
```

when no useful pillar is detected.

<div align="center">

| Packet Part | Purpose |
| :--- | :--- |
| **Color code** | Determine obstacle rule |
| **xCenter** | Determine horizontal pillar location |
| **width** | Estimate visual size / approach state |
| **Freshness** | Prevent old data from controlling steering |

</div>

This lets the EV3 reason about both:

```text
WHAT IS THE PILLAR?
```

and:

```text
WHERE IS THE PILLAR?
```

---

# ❀ 3.1.21 Camera Steering Bias Architecture ────୨ৎ────────୨ৎ────

<p align="center">
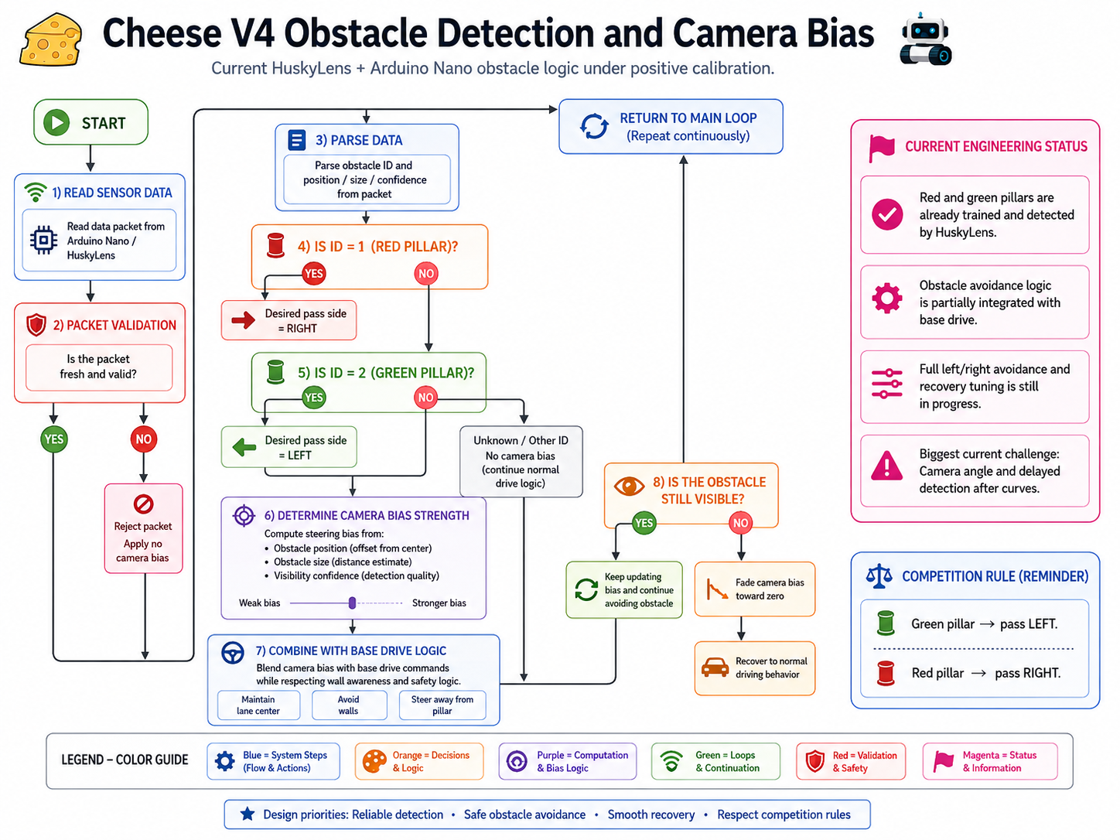
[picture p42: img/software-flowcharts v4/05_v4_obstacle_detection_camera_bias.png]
Cheese v4 obstacle camera steering bias
  
</p>

The camera does not replace normal navigation.

Instead:

```text
NORMAL STEERING
      +
CAMERA BIAS
      ↓
SAFETY LIMIT
      ↓
FINAL STEERING
```

Important camera-response mechanisms include:

- fresh-packet validation,
- minimum useful detection size,
- color-specific passing rule,
- xCenter-based response,
- width-based response,
- smoothing,
- approach-speed reduction,
- wall-clearance limitation,
- and lost-pillar reset.

---

# ❀ 3.1.22 Why Camera Bias Is Limited ────୨ৎ────────୨ৎ────

Suppose the camera requests:

```text
MOVE RIGHT
```

but the right ultrasonic detects:

```text
RIGHT WALL DANGEROUS
```

If both systems had unlimited authority, Cheese could receive contradictory commands.

The architecture therefore aims for:

```text
CAMERA REQUEST
      ↓
CHECK SAFETY
      ↓
SAFE?
 ┌────┴────┐
YES        NO
│           │
ALLOW      LIMIT
```

This is one of the central systems-design decisions in the obstacle controller.

---

# ❀ 3.1.23 Camera Geometry as Part of the Algorithm ────୨ৎ────────୨ৎ────

<p align="center">
  Cheese v4 HuskyLens viewing angle
</p>

<p align="center">
  <em>
    Current HuskyLens viewing angle used during obstacle navigation.
  </em>
</p>

Camera performance depends on physical geometry.

```text
ROBOT HEADING
      ↓
CAMERA FIELD OF VIEW
      ↓
PILLAR POSITION IN IMAGE
      ↓
VISION DATA
      ↓
STEERING RESPONSE
```

Therefore a vision failure may not originate inside the camera.

It can begin with a poor robot trajectory.

---

# ❀ 3.1.24 Obstacle Avoidance Architecture ────୨ৎ────────୨ৎ────

A successful obstacle sequence requires:

```text
DETECT
 ↓
IDENTIFY
 ↓
REACT EARLY
 ↓
CLEAR
 ↓
REMOVE OLD BIAS
 ↓
RECOVER
 ↓
CONTINUE
```

Detection is only one stage.

The physical maneuver must still produce enough clearance to avoid contact.

---

# ❀ 3.1.25 Recovery Architecture ────୨ৎ────────୨ৎ────

Recovery is currently one of the most important obstacle-development areas.

The ideal sequence is:

```text
PILLAR CLEARED
      ↓
CAMERA BIAS REDUCES
      ↓
NORMAL NAVIGATION RETURNS
      ↓
ROBOT STABILIZES
      ↓
NEXT PILLAR ENTERS USEFUL FOV
```

A poor recovery can create:

```text
BAD EXIT ANGLE
      ↓
NEXT PILLAR APPEARS LATE
      ↓
LATE DETECTION
      ↓
FAILED NEXT AVOIDANCE
```

This means recovery is part of both **movement** and **future perception**.

---

# ❀ 3.1.26 Speed as a Control Variable ────୨ৎ────────୨ৎ────

Speed changes how much time the robot has to react.

Current Open values include:

<div align="center">

| State | Speed |
| :--- | :---: |
| Normal drive | `-62` |
| Gentle wall response | `-44` |
| Severe wall response | `-24` |
| Parking | `-28` |
| Parking medium | `-18` |
| Parking creep | `-10` |
| Emergency reverse | `28` |

</div>

The architecture therefore treats speed as part of the current control state.

```text
SAFE
 ↓
FASTER

DANGER
 ↓
SLOWER

PARKING
 ↓
PRECISE

EMERGENCY
 ↓
REVERSE
```

---

# ❀ 3.1.27 Software + Mechanical Feedback Loop ────୨ৎ────────୨ৎ────

The algorithm works inside a physical feedback loop.

```text
SOFTWARE REQUEST
      ↓
STEERING MOTOR
      ↓
LINKAGE
      ↓
WHEELS
      ↓
ROBOT MOVES
      ↓
SENSOR GEOMETRY CHANGES
      ↓
NEW INPUT
      ↓
SOFTWARE
```

This is why changes in:

- steering friction,
- linkage geometry,
- robot mass,
- wheel traction,
- sensor position,
- or battery condition

can change software behavior without changing one line of code.

---

# ❀ 3.1.28 Battery as a Systems Variable ────୨ৎ────────୨ৎ────

Battery condition can affect:

- drive strength,
- steering speed,
- acceleration,
- reverse recovery,
- and obstacle-response timing.

Therefore:

```text
FAILED TEST
   ≠
AUTOMATICALLY BAD CODE
```

The team considers several possible causes:

```text
SOFTWARE?
SENSOR?
MECHANICS?
BATTERY?
CAMERA ANGLE?
TRACK POSITION?
```

before changing control constants.

---

# ❀ 3.1.29 Full Software Architecture Flowchart ────୨ৎ────────୨ৎ────

<p align="center">
  Cheese v4 complete software architecture flowchart
</p>

<p align="center">
  <em>
    Complete Cheese v4 architecture connecting sensing, validation,
    navigation, safety, vision and parking.
  </em>
</p>

The complete control philosophy can be summarized as:

```text
SENSE
 ↓
VALIDATE
 ↓
REMEMBER
 ↓
INTERPRET
 ↓
PRIORITIZE
 ↓
ACT
 ↓
RECOVER
 ↓
REPEAT
```

---

# ❀ 3.1.30 Failure → Architecture Change ────୨ৎ────────୨ৎ────

The current architecture developed through repeated failure analysis.

<div align="center">

| Failure | Interpretation | Architecture Change | Current Result |
| :--- | :--- | :--- | :--- |
| Zig-zag on straights | Too much correction | Minimum-correction PID | Straighter default movement |
| Wall approached too closely | Normal PID insufficient | Progressive wall protection | Earlier response |
| Front wall trapped robot | No room to steer | Reverse recovery | Physical space restored |
| Orange classification varied | Built-in classification inconsistent | Warm-color grouping | Better detection |
| Duplicate curve counts | Raw events trusted too easily | Timing + confirmation + cooldown | Better progress tracking |
| Camera request conflicted with wall | Multiple control systems fighting | Wall-limited camera bias | Safer obstacle control |
| Old obstacle steering continued | Stale camera state | Freshness + lost-pillar reset | Cleaner transitions |
| Next pillar appeared late | Poor recovery | Recovery treated as full subsystem | Current obstacle focus |

</div>

The engineering process is:

```text
FAILURE
   ↓
CAUSE
   ↓
RISK
   ↓
ARCHITECTURE CHANGE
   ↓
TEST
   ↓
RESULT
```

---

# ❀ 3.1.31 Current Architecture Status ────୨ৎ────────୨ৎ────

<div align="center">

| Architecture Area | Status |
| :--- | :--- |
| **Motor control** | 🟢 Stable |
| **Ultrasonic input** | 🟢 Functional |
| **Color input** | 🟢 Functional |
| **Sensor filtering** | 🟢 Implemented |
| **Minimum-correction PID** | 🟢 Functional |
| **Wall protection** | 🟢 Functional |
| **Front reverse recovery** | 🟢 Functional |
| **Curve tracking** | 🟢 Functional |
| **Three-lap Open navigation** | 🟢 Mostly reliable |
| **Open parking** | 🟢 Functional |
| **Green = ID 1 recognition** | 🟢 Confirmed |
| **Red = ID 2 recognition** | 🟢 Confirmed |
| **Nano communication** | 🟢 Functional |
| **Camera steering influence** | 🟢 Implemented |
| **Obstacle avoidance consistency** | 🟡 Tuning |
| **Post-obstacle recovery** | 🟠 Main current development area |
| **Obstacle parking** | 🟠 Pending |

</div>

---

# ❀ 3.1.32 Supporting Repository Resources ────୨ৎ────────୨ৎ────

<div align="center">

| Resource | Purpose |
| :--- | :--- |
| [`00_v4_flowchart_set_map.png`](../../img/software-flowcharts%20v4/00_v4_flowchart_set_map.png) | Software subsystem map |
| [`01_v4_main_loop_control_cycle.png`](../../img/software-flowcharts%20v4/01_v4_main_loop_control_cycle.png) | Main control loop |
| [`02_v4_color_detection_curve_counting.png`](../../img/software-flowcharts%20v4/02_v4_color_detection_curve_counting.png) | Curve-count logic |
| [`03_v4_minimum_correction_pid_controller.png`](../../img/software-flowcharts%20v4/03_v4_minimum_correction_pid_controller.png) | PID architecture |
| [`04_v4_front_wall_safety_reverse_recovery.png`](../../img/software-flowcharts%20v4/04_v4_front_wall_safety_reverse_recovery.png) | Safety recovery |
| [`05_v4_obstacle_detection_camera_bias.png`](../../img/software-flowcharts%20v4/05_v4_obstacle_detection_camera_bias.png) | Vision steering architecture |
| [`06_v4_parking_finish_logic.png`](../../img/software-flowcharts%20v4/06_v4_parking_finish_logic.png) | Parking architecture |
| [`07_v4_sensor_validation_reliability.png`](../../img/software-flowcharts%20v4/07_v4_sensor_validation_reliability.png) | Sensor validation |
| [`08_v4_main_software_flowchart.png`](../../img/software-flowcharts%20v4/08_v4_main_software_flowchart.png) | Complete architecture |
| [`huskylens_green_id1_detection_v4.png`](../../v-photos/v4/huskylens_green_id1_detection_v4.png) | Current green recognition evidence |
| [`huskylens_red_id2_detection_v4.png`](../../v-photos/v4/huskylens_red_id2_detection_v4.png) | Current red recognition evidence |

</div>

<p align="center">
  <a href="https://quesovamos2662.github.io/WRO2026_FE_Go-Cheese/embeds/v4_software_priority_chain.html">
    
  </a>

  <a href="https://quesovamos2662.github.io/WRO2026_FE_Go-Cheese/embeds/v4_sensor_configuration.html">
    
  </a>

  <a href="https://quesovamos2662.github.io/WRO2026_FE_Go-Cheese/embeds/v4_obstacle_testing_status.html">
    
  </a>
</p>

---

# ❀ 3.1.33 v3 → v4 Architecture Evolution ────୨ৎ────────୨ৎ────

Earlier software remains useful as engineering history, but the active reference is Cheese v4.

<div align="center">

| Area | Earlier Direction | Current v4 Direction |
| :--- | :--- | :--- |
| **Straight navigation** | More continuous correction | Minimum correction |
| **Wall response** | More dependent on general steering | Progressive protection |
| **Front safety** | Less independent | Dedicated reverse recovery |
| **Color logic** | Earlier experimental approaches | Current `COL-COLOR` grouping |
| **Distance sensing** | Earlier configurations | Three-ultrasonic architecture |
| **Vision** | Earlier camera experimentation | HuskyLens + Nano data path |
| **Obstacle response** | Less integrated | Camera steering influence |
| **Recovery** | Less explicit | Treated as a full subsystem |

</div>

The v4 architecture is simpler in concept:

<p align="center">
  <strong>
    Use each sensor for a clear purpose and give each control behavior a defined level of authority.
  </strong>
</p>

---

# ✦ Engineering Lessons ─── ⋆⋅☆⋅⋆ ───

### 1. Architecture matters as much as individual algorithms

A good PID and a good camera controller can still fail if they fight each other.

---

### 2. Sensors should provide information, not uncontrolled authority

The software decides how much each sensor should influence movement.

---

### 3. Validation should happen before action

One unreliable reading should not be enough to create a major steering change.

---

### 4. Minimum correction can improve stability

Not every small deviation deserves a response.

---

### 5. Physical safety needs its own behavior

Sometimes reversing is more useful than steering harder.

---

### 6. Vision depends on robot geometry

Camera field of view changes with the robot's heading and previous movement.

---

### 7. Recovery is part of the algorithm

The next maneuver depends on the position created by the previous maneuver.

---

### 8. Real evidence must match software documentation

The current camera evidence confirms:

```text
GREEN = ID 1
RED   = ID 2
```

so the software documentation must preserve that exact mapping.

---

# ✦ 3.1 Algorithm Architecture Summary ─── ⋆⋅☆⋅⋆ ───

Cheese v4 uses a **priority-based, sensor-driven, minimum-correction architecture**.

The Open Challenge combines:

- three ultrasonic sensors,
- floor-color tracking,
- sensor validation,
- PID navigation,
- progressive wall protection,
- front reverse recovery,
- validated curve counting,
- and distance-based parking.

The Obstacle Challenge adds:

- HuskyLens vision,
- Arduino Nano communication,
- **Green = ID 1** recognition,
- **Red = ID 2** recognition,
- camera-based steering influence,
- color-specific passing rules,
- wall-aware obstacle response,
- and post-obstacle recovery.

The architecture can therefore be summarized as:

<p align="center">
  <strong>
    Sense → Validate → Remember → Prioritize → Control → Recover → Repeat
  </strong>
</p>

<p align="center">
  ✦ ─── ⋆⋅☆⋅⋆ ─── 🧀 Algorithm Architecture Vault 🧀 ─── ⋆⋅☆⋅⋆ ─── ✦
</p>

<p align="center">
  <a href="https://github.com/Quesovamos2662/WRO2026_FE_Go-Cheese#general-project-index">
    
  </a>
</p>

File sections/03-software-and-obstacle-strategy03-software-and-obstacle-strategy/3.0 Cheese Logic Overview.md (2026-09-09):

<h1 align="center">ᯓ★ 3.0 Cheese Logic Overview ᯓ★</h1>

<p align="center">
  
  
  
  
</p>

<p align="center">
  <em>
    A high-level overview of how Cheese v4 senses the field,
    interprets its environment, chooses a response,
    moves, recovers, and tracks progress during the WRO Future Engineers challenges.
  </em>
</p>

<p align="center">
  ✦ ─── ⋆⋅☆⋅⋆ ─── 🧀🤖 ─── ⋆⋅☆⋅⋆ ─── ✦
</p>

---

# ❀ 3.0.1 Software Philosophy ────୨ৎ────────୨ৎ────

Cheese v4 is controlled through a **sensor-driven, priority-based architecture**.

The software does not simply execute a fixed sequence such as:

```text
DRIVE 3 SECONDS
TURN
DRIVE 5 SECONDS
TURN
```

Instead, Cheese continuously observes what is happening around it.

```text
SENSE
  ↓
VALIDATE
  ↓
INTERPRET
  ↓
DECIDE
  ↓
ACT
  ↓
RECOVER
  ↓
REPEAT
```

This allows the robot to respond to the real field rather than assuming that every lap, curve, wall distance, or obstacle will appear exactly the same.

The central philosophy is:

<p align="center">
  <strong>
    Correct only when necessary, protect the robot when danger increases,
    and always prepare the next movement before the current one is considered complete.
  </strong>
</p>

---

# ❀ 3.0.2 Two Challenge Modes ────୨ৎ────────୨ৎ────

Cheese v4 currently uses two related but separate software systems.

<div align="center">

| Challenge | Main Objective | Current Status |
| :--- | :--- | :--- |
| 🟦 **Open Challenge** | Complete three laps, count curves and return to parking | 🟢 Near-final calibration |
| 🚧 **Obstacle Challenge** | Navigate while detecting and avoiding red / green pillars | 🟡 Active development |

</div>

Both modes share the same basic engineering principle:

```text
READ ENVIRONMENT
      ↓
UNDERSTAND CURRENT SITUATION
      ↓
CHOOSE USEFUL CONTROL
      ↓
MOVE
      ↓
READ AGAIN
```

However, their priorities are different.

---

# ❀ 3.0.3 Current Software Files ────୨ৎ────────୨ৎ────

The current development files are:

<div align="center">

| Challenge | Current Main File |
| :--- | :--- |
| **Open Challenge** | `GOOD_CURVE_COUNTER_TEST11_PROGRESSIVE_ESCAPE_REVERSE_RETRACE.py` |
| **Obstacle Challenge** | `GOODYIPEE (1)(3) (21).py` |

</div>

The Open file contains the more mature navigation system.

It currently handles:

- ultrasonic navigation,
- color-based curve counting,
- minimum-correction PID,
- progressive wall protection,
- front-wall recovery,
- three-lap progress,
- and final parking.

The Obstacle file extends the navigation system with:

- HuskyLens vision,
- Arduino Nano communication,
- red / green pillar detection,
- camera-based steering influence,
- obstacle avoidance,
- and recovery testing.

Keeping these files separate protects the more stable Open system while the obstacle strategy continues to evolve.

---

# ❀ 3.0.4 Software Architecture Map ────୨ৎ────────୨ৎ────

The software is divided into several connected subsystems.

<p align="center">
  Cheese v4 software flowchart set map
</p>

<p align="center">
  <em>
    Overview of the main Cheese v4 software subsystems documented throughout Section 3.
  </em>
</p>

The architecture can be viewed as:

```text
                 ┌──────────────────┐
                 │     SENSORS      │
                 └────────┬─────────┘
                          ↓
                 ┌──────────────────┐
                 │    VALIDATION    │
                 └────────┬─────────┘
                          ↓
                 ┌──────────────────┐
                 │  INTERPRETATION  │
                 └────────┬─────────┘
                          ↓
                 ┌──────────────────┐
                 │    PRIORITIES    │
                 └────────┬─────────┘
                          ↓
        ┌─────────────────┼─────────────────┐
        ↓                 ↓                 ↓
   NAVIGATION          SAFETY           PROGRESS
        │                 │                 │
        └─────────────────┼─────────────────┘
                          ↓
                   MOTOR OUTPUT
                          ↓
                     MOVEMENT
                          ↓
                     NEW DATA
```

In Obstacle mode, vision becomes an additional branch before the final steering command.

---

# ❀ 3.0.5 Main Hardware Inputs ────୨ৎ────────୨ৎ────

Cheese v4 uses several sensors because no single sensor can describe the entire field.

<p align="center">
  Cheese v4 sensor layout
</p>

<p align="center">
  <em>
    Current Cheese v4 sensing architecture combining lateral distance,
    forward safety, floor detection and vision.
  </em>
</p>

<div align="center">

| Sensor / Device | Main Software Role |
| :--- | :--- |
| **Left Ultrasonic** | Measures left-side wall distance |
| **Right Ultrasonic** | Measures right-side wall distance |
| **Front Ultrasonic** | Detects dangerous forward proximity |
| **EV3 Color Sensor** | Detects floor markers and tracks curves |
| **HuskyLens** | Detects colored pillars during Obstacle mode |
| **Arduino Nano** | Transfers simplified HuskyLens information to the EV3 |

</div>

The software combines these inputs instead of expecting one sensor to solve every navigation problem.

---

# ❀ 3.0.6 Main Hardware Outputs ────୨ৎ────────୨ৎ────

Cheese has two primary motor outputs.

<div align="center">

| Motor | Function |
| :--- | :--- |
| **Large Motor** | Rear-wheel propulsion |
| **Medium Motor** | Front Ackermann steering |

</div>

The software ultimately converts every decision into:

```text
DRIVE SPEED
     +
STEERING ANGLE
     ↓
PHYSICAL MOVEMENT
```

The next sensor readings are then affected by that movement.

This creates a closed control loop.

---

# ❀ 3.0.7 Main Control Loop ────୨ৎ────────୨ৎ────

<p align="center">
  Cheese v4 main software control loop
</p>

<p align="center">
  <em>
    Repeated control cycle used to continuously update Cheese's movement.
  </em>
</p>

At a high level:

```text
START
  ↓
READ SENSORS
  ↓
CHECK SAFETY
  ↓
UPDATE PROGRESS
  ↓
CALCULATE NAVIGATION
  ↓
APPLY ALLOWED VISION RESPONSE
  ↓
COMMAND MOTORS
  ↓
CHECK FINISH
  ↓
REPEAT
```

The robot therefore does not make one decision per curve.

It repeatedly updates its decision while moving.

---

# ❀ 3.0.8 Sensor Validation ────୨ৎ────────୨ৎ────

A major part of Cheese's logic is deciding whether information is trustworthy enough to use.

<p align="center">
  Cheese v4 sensor validation and reliability logic
</p>

The general concept is:

```text
RAW SENSOR VALUE
       ↓
IS IT VALID?
   ┌───┴───┐
  NO      YES
  │         │
IGNORE    FILTER
            ↓
        INTERPRET
            ↓
          USE
```

Examples include:

- filtering ultrasonic readings,
- validating floor-color sequences,
- requiring curve confirmation,
- confirming dangerous front distances,
- checking whether camera data is fresh,
- and clearing outdated obstacle commands.

This reduces the chance that one incorrect sample creates a large physical reaction.

---

# ❀ 3.0.9 Open Challenge Logic ────୨ৎ────────୨ৎ────

The Open Challenge is currently the most stable navigation mode.

Its high-level logic is:

```text
START
  ↓
SAVE STARTING DISTANCES
  ↓
DRIVE
  ↓
READ SIDE ULTRASONICS
  ↓
PID / WALL PROTECTION
  ↓
READ FLOOR COLOR
  ↓
VALID CURVE?
  ↓
UPDATE CURVE COUNT
  ↓
FRONT DANGER?
  ↓
RECOVER IF NEEDED
  ↓
12 CURVES?
  ↓
RETURN TO START REGION
  ↓
PARK
```

The Open system is explained in detail in **Section 3.3 Open Challenge**.

---

# ❀ 3.0.10 Minimum-Correction Navigation ────୨ৎ────────୨ৎ────

Cheese does not continuously force itself toward an exact mathematical center.

The controller instead asks:

```text
IS THE CURRENT PATH SAFE?
```

If yes:

```text
KEEP MOVING
```

If useful correction is needed:

```text
APPLY PID
```

If danger becomes greater:

```text
INCREASE PROTECTION
```

<p align="center">
  Cheese v4 minimum correction PID controller
</p>

This architecture was developed to reduce unnecessary zig-zag and steering conflict.

---

# ❀ 3.0.11 Progressive Wall Protection ────୨ৎ────────୨ৎ────

Wall response is not simply:

```text
SAFE / CRASH
```

It becomes stronger as the situation becomes more dangerous.

```text
NORMAL DISTANCE
      ↓
NORMAL NAVIGATION

CLOSER
      ↓
GENTLE PROTECTION

TOO CLOSE
      ↓
SEVERE PROTECTION

CRITICAL
      ↓
STRONG AVOIDANCE / RECOVERY
```

This gives Cheese multiple opportunities to correct its trajectory before contact occurs.

---

# ❀ 3.0.12 Front Safety and Reverse Recovery ────୨ৎ────────୨ৎ────

The front ultrasonic provides a separate safety mechanism.

<p align="center">
  Cheese v4 front ultrasonic sensor
</p>

<p align="center">
  <em>
    Front ultrasonic sensor used to detect dangerous forward proximity.
  </em>
</p>

If the robot gets too close to a wall:

```text
FRONT DANGER
      ↓
CONFIRM
      ↓
REVERSE
      ↓
CREATE PHYSICAL SPACE
      ↓
RETURN TO NAVIGATION
```

<p align="center">
  Cheese v4 front-wall safety and reverse recovery
</p>

This is important because a steering command cannot help if Cheese is already physically trapped against a wall.

---

# ❀ 3.0.13 Color-Based Progress Tracking ────୨ৎ────────୨ৎ────

The EV3 Color Sensor tracks progress through the Open course.

<p align="center">
  Cheese v4 floor-facing color sensor
</p>

<p align="center">
  <em>
    Current color sensor position used for track-event detection.
  </em>
</p>

The software interprets:

```text
BLUE
```

and groups several warm EV3 classifications as:

```text
ORANGE
```

A curve requires a valid transition such as:

```text
BLUE → ORANGE
```

or:

```text
ORANGE → BLUE
```

<p align="center">
  Cheese v4 color detection and curve counting
</p>

The complete Open run requires:

```text
4 CURVES
   ×
3 LAPS
   =
12 CURVES
```

This count determines when parking is allowed to begin.

---

# ❀ 3.0.14 Open Parking Logic ────୨ৎ────────୨ৎ────

Parking does not depend only on elapsed time.

Cheese stores environmental information at the start.

After completing the required progress:

```text
12 CURVES
    ↓
PARKING ENABLED
    ↓
RETURN TOWARD START REGION
    ↓
COMPARE CURRENT DISTANCE
WITH SAVED START REFERENCE
    ↓
SLOW APPROACH
    ↓
STOP
```

<p align="center">
  Cheese v4 parking and finish logic
</p>

This links:

```text
PROGRESS
   +
POSITION
   ↓
FINISH
```

rather than relying only on timing.

---

# ❀ 3.0.15 Obstacle Challenge Logic ────୨ৎ────────୨ৎ────

Obstacle mode adds vision to the navigation architecture.

The high-level process becomes:

```text
NORMAL NAVIGATION
       ↓
PILLAR DETECTED?
       ↓
IDENTIFY COLOR
       ↓
DETERMINE PASSING SIDE
       ↓
APPLY CAMERA STEERING INFLUENCE
       ↓
CLEAR PILLAR
       ↓
REMOVE OLD CAMERA INFLUENCE
       ↓
RECOVER
       ↓
CONTINUE
```

The Obstacle Challenge is explained in detail in **Section 3.4**.

---

# ❀ 3.0.16 Current HuskyLens Detection Evidence ────୨ৎ────────୨ৎ────

The current vision system has been physically tested with both competition pillar colors.

<p align="center">
  HuskyLens detecting the green obstacle as Color ID 1
  &nbsp;
  HuskyLens detecting the red obstacle as Color ID 2
</p>

<p align="center">
  <em>
    Current physical HuskyLens recognition evidence:
    green is detected as Color ID 1 and red as Color ID 2.
  </em>
</p>

The current trained vision classes shown during testing are:

<div align="center">

| Physical Pillar | Current HuskyLens Detection |
| :--- | :---: |
| 🟢 **Green** | **Color ID 1** |
| 🔴 **Red** | **Color ID 2** |

</div>

This visual evidence is important because it verifies the actual camera configuration instead of documenting only the intended software behavior.

---

# ❀ 3.0.17 Physical Obstacle References ────୨ৎ────────୨ৎ────

The team tests recognition and avoidance using physical red and green pillar models.

<p align="center">
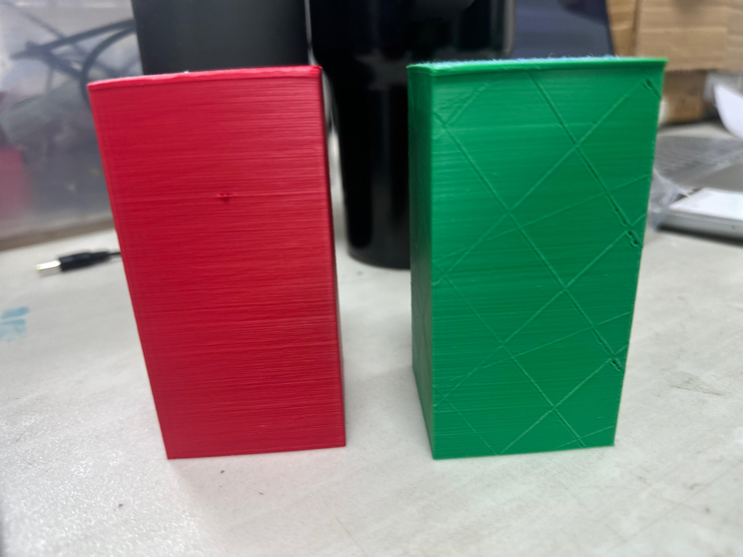
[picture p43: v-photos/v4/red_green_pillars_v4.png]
Red and green obstacle pillars used during Cheese v4 testing
  
</p>

<p align="center">
  <em>
    Physical red and green pillars used during vision and obstacle-navigation development.
  </em>
</p>

The obstacle rules require different trajectories depending on pillar color.

```text
GREEN
  ↓
PASS LEFT
```

```text
RED
  ↓
PASS RIGHT
```

Therefore the software must connect:

```text
COLOR
  ↓
RULE
  ↓
STEERING RESPONSE
```

---

# ❀ 3.0.18 Vision Communication Architecture ────୨ৎ────────୨ৎ────

The HuskyLens does not communicate directly with the main Python navigation logic.

Instead:

```text
HUSKYLENS
    ↓
I²C
    ↓
ARDUINO NANO
    ↓
USB SERIAL
    ↓
EV3
```

<p align="center">
  Arduino Nano position on Cheese v4
  &nbsp;
  EV3 USB connection to Arduino Nano
</p>

<p align="center">
  <em>
    Arduino Nano bridge and USB communication path used by the current vision system.
  </em>
</p>

The Nano converts camera information into a simpler form for the EV3.

Conceptually:

```text
CAMERA DATA
     ↓
NANO
     ↓
COLOR + POSITION + SIZE
     ↓
EV3
```

---

# ❀ 3.0.19 Camera Steering Influence ────୨ৎ────────୨ৎ────

The camera does not receive unlimited steering authority.

<p align="center">
  Cheese v4 obstacle detection and camera steering bias
</p>

The architecture is approximately:

```text
NORMAL NAVIGATION
       +
CAMERA BIAS
       ↓
WALL SAFETY
       ↓
FINAL STEERING
```

This means:

- vision can influence the trajectory,
- wall sensors remain relevant,
- unsafe camera commands can be limited,
- and old camera influence should disappear after the obstacle is lost.

---

# ❀ 3.0.20 Why Camera Position Matters ────୨ৎ────────୨ৎ────

<p align="center">
  Cheese v4 HuskyLens viewing angle
</p>

<p align="center">
  <em>
    Current HuskyLens viewing angle used during obstacle detection.
  </em>
</p>

Vision reliability depends on robot geometry.

```text
GOOD ROBOT HEADING
      ↓
PILLAR ENTERS CAMERA EARLY
      ↓
EARLIER DETECTION
      ↓
MORE TIME TO AVOID
```

But:

```text
BAD EXIT ANGLE
      ↓
PILLAR ENTERS CAMERA LATE
      ↓
LESS REACTION TIME
      ↓
HARDER AVOIDANCE
```

This is why camera placement, steering, curves and recovery must be developed together.

---

# ❀ 3.0.21 Obstacle Recovery ────୨ৎ────────୨ৎ────

The current obstacle-development priority is not simply recognizing colors.

The larger challenge is:

```text
DETECT
  ↓
AVOID
  ↓
CLEAR
  ↓
RECOVER
  ↓
PREPARE FOR NEXT PILLAR
```

A pillar can be avoided successfully while the overall maneuver still fails.

For example:

```text
PILLAR 1 CLEARED
      ↓
BAD EXIT ANGLE
      ↓
NEXT PILLAR ENTERS FOV LATE
      ↓
NEXT AVOIDANCE FAILS
```

Therefore recovery is considered part of obstacle avoidance itself.

---

# ❀ 3.0.22 Current Real Obstacle Testing ────୨ৎ────────୨ৎ────

<p align="center">
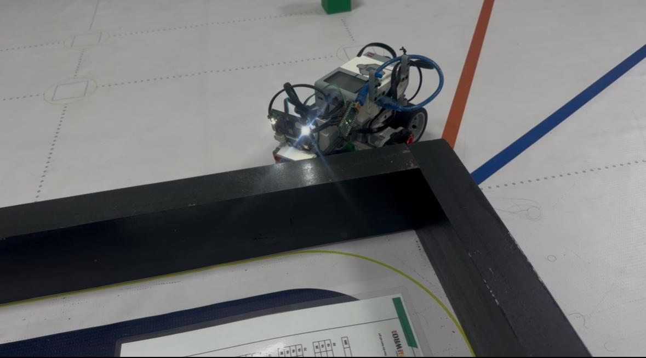
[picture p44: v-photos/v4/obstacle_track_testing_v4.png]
Cheese v4 during obstacle challenge track testing
  
</p>

<p align="center">
  <em>
    Cheese v4 during physical obstacle-field testing with a green pillar present on the course.
  </em>
</p>

Real-field testing combines:

```text
CAMERA
 +
PILLARS
 +
WALLS
 +
STEERING
 +
SPEED
 +
FIELD OF VIEW
 +
RECOVERY
      ↓
REAL OBSTACLE PERFORMANCE
```

This image belongs to the **Obstacle Challenge evidence**, not the Open Challenge.

---

# ❀ 3.0.23 Behavior Priority ────୨ৎ────────୨ৎ────

Not every software behavior should have equal authority.

A simplified priority chain is:

```text
CRITICAL SAFETY
      ↓
WALL PROTECTION
      ↓
VALID NAVIGATION / PROGRESS
      ↓
VISION RESPONSE
      ↓
NORMAL MOVEMENT
```

Parking becomes a finishing priority once the required run progress is complete.

The goal is to prevent conflicting commands such as:

```text
CAMERA REQUESTS RIGHT
        +
RIGHT WALL IS DANGEROUS
        ↓
DO NOT BLINDLY FOLLOW CAMERA
```

---

# ❀ 3.0.24 Speed Is Part of the Logic ────୨ৎ────────୨ৎ────

Speed is not treated as a completely separate variable.

It changes how much time the robot has to:

- detect,
- calculate,
- steer,
- clear a wall,
- avoid a pillar,
- and recover.

The basic strategy is:

```text
SAFE
 ↓
FASTER

HIGHER RISK
 ↓
SLOWER

FINAL PARKING
 ↓
PRECISE

EMERGENCY
 ↓
REVERSE
```

This is especially important during obstacle testing because faster movement reduces the time between first useful detection and physical contact with a pillar.

---

# ❀ 3.0.25 Software Is Connected to Mechanics ────୨ৎ────────୨ৎ────

Software commands do not directly move Cheese through mathematics alone.

They act through physical components.

```text
SOFTWARE
    ↓
MEDIUM MOTOR
    ↓
ACKERMANN LINKAGE
    ↓
FRONT WHEELS
    ↓
ROBOT CHANGES HEADING
    ↓
SENSOR VIEW CHANGES
    ↓
SOFTWARE
```

This means that:

- steering geometry,
- motor response,
- robot mass,
- sensor placement,
- wheel traction,
- and battery condition

all affect the behavior of the same code.

---

# ❀ 3.0.26 Battery Condition ────୨ৎ────────୨ৎ────

Battery condition can change the physical response of Cheese even if the program itself is unchanged.

Possible effects include:

```text
LOWER MOTOR RESPONSE
        ↓
DIFFERENT TURN
        ↓
DIFFERENT SENSOR POSITION
        ↓
DIFFERENT NEXT DECISION
```

Therefore the team does not automatically assume:

```text
FAILED TEST = BAD CODE
```

Instead, testing considers:

```text
SOFTWARE?
SENSOR?
MECHANICS?
BATTERY?
CAMERA ANGLE?
TRACK POSITION?
```

This is especially important when comparing repeated runs.

---

# ❀ 3.0.27 Current Software Status ────୨ৎ────────୨ৎ────

<div align="center">

| System | Status |
| :--- | :--- |
| **EV3 motor control** | 🟢 Stable |
| **Ultrasonic sensing** | 🟢 Functional |
| **Color sensing** | 🟢 Functional |
| **Sensor filtering** | 🟢 Implemented |
| **Minimum-correction PID** | 🟢 Functional |
| **Progressive wall protection** | 🟢 Functional |
| **Front reverse recovery** | 🟢 Functional |
| **Curve counting** | 🟢 Functional |
| **Three-lap Open navigation** | 🟢 Mostly reliable |
| **Open parking** | 🟢 Functional |
| **Green HuskyLens detection** | 🟢 Confirmed |
| **Red HuskyLens detection** | 🟢 Confirmed |
| **Nano communication** | 🟢 Functional |
| **Camera steering influence** | 🟢 Implemented |
| **Obstacle avoidance consistency** | 🟡 In calibration |
| **Post-obstacle recovery** | 🟠 Main current challenge |
| **Obstacle parking** | 🟠 Pending stabilization |

</div>

---

# ❀ 3.0.28 Software Development Method ────୨ৎ────────୨ৎ────

Cheese's software was developed through repeated testing rather than one final program written from the beginning.

The team's preferred development cycle is:

```text
OBSERVE FAILURE
      ↓
IDENTIFY CAUSE
      ↓
IDENTIFY RISK
      ↓
CHANGE ONE SYSTEM
      ↓
TEST
      ↓
COMPARE RESULT
      ↓
KEEP / REJECT CHANGE
```

This allows software decisions to be supported by physical behavior.

---

# ❀ 3.0.29 Failure → Cause → Fix Examples ────୨ৎ────────୨ৎ────

<div align="center">

| Observation | Cause / Interpretation | Engineering Change | Result / Current Direction |
| :--- | :--- | :--- | :--- |
| Zig-zag on straights | Excessive correction | Minimum-correction PID | Straighter normal motion |
| Wall approached too closely | Normal correction insufficient | Progressive wall protection | Earlier safety response |
| Robot became trapped near front wall | Steering lacked physical space | Reverse recovery | Space created before continuing |
| Orange classification varied | EV3 warm-color interpretation | Grouped warm colors | More tolerant curve detection |
| Curve could count twice | One physical event created multiple readings | Cooldown + validation | Better progress tracking |
| Pillar seen but still contacted | Detection did not create enough physical clearance | Tune approach + avoidance | Active obstacle calibration |
| Next pillar appeared too late | Previous recovery left bad heading | Treat recovery as part of avoidance | Main current obstacle focus |

</div>

The important engineering chain is:

```text
FAILURE
   ↓
CAUSE
   ↓
RISK
   ↓
FIX
   ↓
TEST
   ↓
RESULT
   ↓
LEARNING
```

---

# ❀ 3.0.30 Section 3 Roadmap ────୨ৎ────────୨ৎ────

This overview introduces the systems that are explained in greater detail throughout Section 3.

<div align="center">

| Section | Focus |
| :--- | :--- |
| **3.0** | Cheese Logic Overview |
| **3.1** | Algorithm Architecture |
| **3.2** | Flowchart |
| **3.3** | Open Challenge |
| **3.4** | Obstacle Challenge |
| **3.5** | Corner Handling |
| **3.6** | Tuning Process |

</div>

The sections move from:

```text
GENERAL LOGIC
      ↓
ARCHITECTURE
      ↓
VISUAL FLOW
      ↓
OPEN STRATEGY
      ↓
OBSTACLE STRATEGY
      ↓
CORNER BEHAVIOR
      ↓
TESTING + TUNING
```

---

# ✦ Engineering Lessons ─── ⋆⋅☆⋅⋆ ───

### 1. A robot should not react to every sensor value equally

Information must first be validated and interpreted.

---

### 2. Stable navigation often requires less correction

Continuous steering can create the instability it is trying to remove.

---

### 3. Safety must have authority over normal navigation

When Cheese is physically close to collision, normal steering may no longer be enough.

---

### 4. Progress tracking affects the entire run

A curve-counting error can eventually become a parking error.

---

### 5. Camera recognition alone does not solve obstacles

A successful obstacle maneuver requires detection, reaction, clearance and recovery.

---

### 6. The robot's movement changes its next sensor input

Steering changes wall distances and camera field of view.

Software and mechanics therefore form one closed system.

---

### 7. Recovery is preparation

The end of one maneuver determines the starting conditions of the next one.

---

# ✦ 3.0 Cheese Logic Summary ─── ⋆⋅☆⋅⋆ ───

Cheese v4 uses a **sensor-driven, priority-based and minimum-correction control philosophy**.

The Open Challenge combines:

- three ultrasonic sensors,
- floor-color detection,
- minimum-correction PID,
- progressive wall protection,
- front reverse recovery,
- validated curve counting,
- three-lap progress tracking,
- and final parking.

The Obstacle Challenge adds:

- HuskyLens vision,
- Arduino Nano communication,
- physical red / green recognition,
- camera steering influence,
- pillar-specific passing rules,
- wall-aware obstacle avoidance,
- and post-obstacle recovery.

Current physical vision evidence confirms:

```text
GREEN = Color ID 1
RED   = Color ID 2
```

The overall Cheese v4 software philosophy can therefore be summarized as:

<p align="center">
  <strong>
    Sense → Validate → Understand → Prioritize → Act → Recover → Repeat
  </strong>
</p>

<p align="center">
  ✦ ─── ⋆⋅☆⋅⋆ ─── 🧀 Cheese Logic Vault 🧀 ─── ⋆⋅☆⋅⋆ ─── ✦
</p>

<p align="center">
  <a href="https://github.com/Quesovamos2662/WRO2026_FE_Go-Cheese#general-project-index">
    
  </a>
</p>

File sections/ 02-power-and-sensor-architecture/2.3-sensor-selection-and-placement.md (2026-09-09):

<h1 align="center">2.3 Sensor Selection and Placement</h1>

<p align="center">
  
  
  
</p>

<p align="center">
  <em>
    Sensor selection on Cheese v4 was based not only on what each sensor can measure,
    but also on where that information is physically needed on the vehicle.
  </em>
</p>

---

## ❀ 2.3.1 Sensor Architecture ────୨ৎ────────୨ৎ────

Cheese v4 uses multiple sensor types because no single sensor can provide all the information required for autonomous navigation.

The current sensing architecture is divided into three main layers:

```text
DISTANCE SENSING
     ↓
3 × EV3 Ultrasonic Sensors
Left + Right + Front

FLOOR SENSING
     ↓
EV3 Color Sensor

VISION
     ↓
HuskyLens
```

Each layer has a different responsibility.

- The **left and right ultrasonic sensors** provide lateral wall-distance information.
- The **front ultrasonic sensor** provides forward safety information.
- The **color sensor** reads the colored track markings used by the curve-counting system.
- The **HuskyLens** identifies red and green pillars during the Obstacle Challenge.

This separation became important during development because it gives each sensor a specific purpose instead of trying to make one sensor solve every navigation problem.

---

## ❀ 2.3.2 Current Sensor Configuration ────୨ৎ────────୨ৎ────

The current Cheese v4 sensor configuration is:

<div align="center">

| Sensor | Quantity | Position | Main Function |
| :--- | :---: | :--- | :--- |
| **EV3 Ultrasonic Sensor** | 1 | Left side | Left wall-distance information |
| **EV3 Ultrasonic Sensor** | 1 | Right side | Right wall-distance information |
| **EV3 Ultrasonic Sensor** | 1 | Front | Forward safety and proximity |
| **EV3 Color Sensor** | 1 | Low front / floor-facing | Track color and curve-count information |
| **HuskyLens** | 1 | Front, above the forward ultrasonic | Red/green pillar recognition |

</div>

The physical location of every sensor was treated as part of the sensing system itself.

A sensor may work correctly electronically while still producing poor navigation information if:

- it points at the wrong part of the field,
- it is mounted too high or too low,
- part of the robot blocks its view,
- vibration changes its orientation,
- or the robot approaches the object from an angle the sensor cannot observe reliably.

For this reason, **sensor placement and software calibration were developed together**.

---

## ❀ 2.3.3 Overall Sensor Placement ────୨ৎ────────୨ৎ────

<p align="center">
  Cheese v4 side sensor layout
</p>

<p align="center">
  <em>Side sensor layout of Cheese v4 showing how the sensing components are integrated into the chassis.</em>
</p>

The current sensor layout attempts to keep the sensing components relatively low and close to the areas they need to observe.

The two lateral ultrasonic sensors are positioned to observe the side walls.

The front ultrasonic sensor faces the direction of travel.

The color sensor faces downward toward the field.

The HuskyLens is mounted toward the front so that colored pillars can enter its field of view before Cheese reaches them.

This creates a sensing architecture where different physical directions correspond to different navigation questions:

```text
LEFT
  ↓
How close is the left wall?

RIGHT
  ↓
How close is the right wall?

FRONT
  ↓
Is Cheese becoming dangerously close to something ahead?

FLOOR
  ↓
Which track color is Cheese crossing?

CAMERA
  ↓
Is the visible pillar red or green?
```

---

# 2.3.4 Lateral Ultrasonic Sensors

The left and right ultrasonic sensors are the primary distance sensors used for lateral navigation.

Unlike the front ultrasonic sensor, their main role is not emergency stopping.

Instead, they provide information about Cheese's position relative to the walls.

<p align="center">
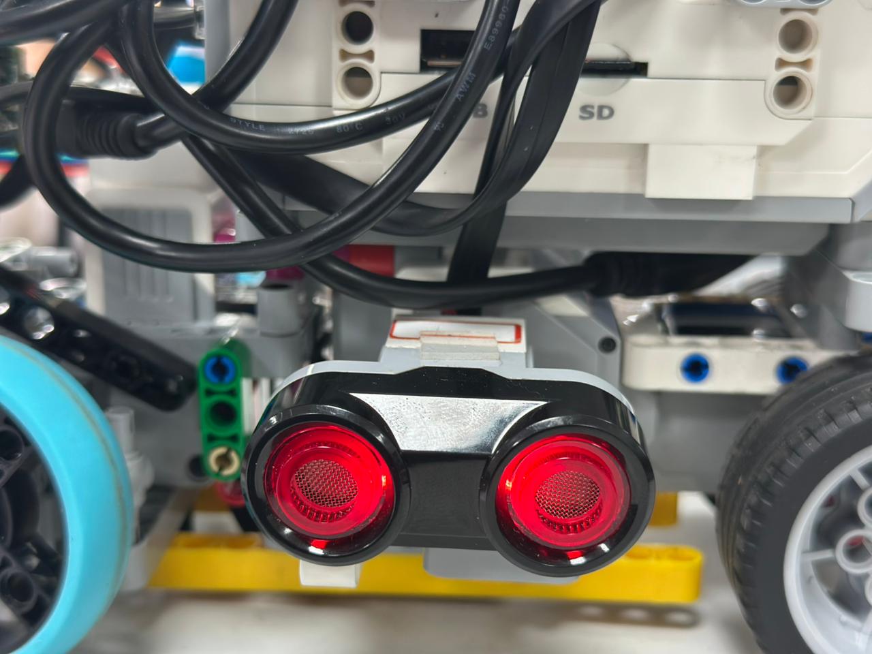
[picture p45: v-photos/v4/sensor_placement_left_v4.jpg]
Cheese v4 left ultrasonic sensor placement
  
  &nbsp;
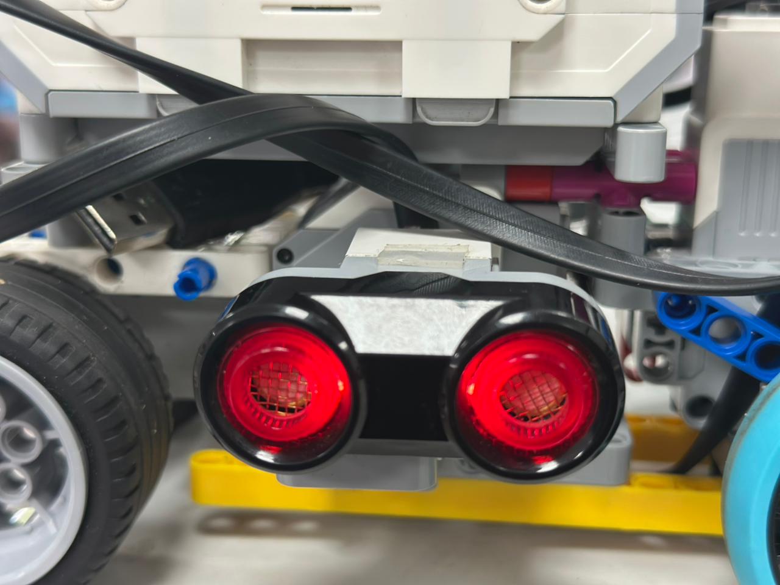
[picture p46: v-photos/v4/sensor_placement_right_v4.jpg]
Cheese v4 right ultrasonic sensor placement
  
</p>

<p align="center">
  <em>Left and right ultrasonic sensor placement on Cheese v4.</em>
</p>

The lateral sensors are mounted so they can continuously measure the surrounding walls while the robot moves through the track.

Their information is used by the navigation software to determine whether Cheese is:

- drifting toward one side,
- moving approximately centered,
- approaching a wall,
- or reaching a distance where stronger wall protection is necessary.

---
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

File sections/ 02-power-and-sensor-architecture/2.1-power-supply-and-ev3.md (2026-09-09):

<h1 align="center">ᯓ★ 2.1 Power Supply & EV3 Architecture ᯓ★</h1>

<p align="center">
  
  
  
</p>

<p align="center">
  <em>
    Cheese v4 uses the LEGO MINDSTORMS EV3 rechargeable battery as its main
    energy source and the EV3 Brick as the central controller of the robot.
  </em>
</p>

<p align="center">
  ✦ ─── ⋆⋅☆⋅⋆ ─── (❁´◡`❁) ─── ⋆⋅☆⋅⋆ ─── ✦
</p>

The power architecture of Cheese v4 was designed around two requirements:

> **Provide enough power for repeatable testing while keeping the EV3 Brick accessible, mechanically stable, and easy to inspect.**
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

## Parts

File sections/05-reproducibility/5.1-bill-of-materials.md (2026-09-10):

<h1 align="center">ᯓ★ 5.1 Bill of Materials — Cheese v4 ᯓ★</h1>

<p align="center">
  
  
  
</p>

<p align="center">
  <em>
    This Bill of Materials documents the current Cheese v4 build, the major
    components used, their quantity, model or reference, function, connection
    and importance for reproducing the robot.
  </em>
</p>

<p align="center">
  ✦ ─── ⋆⋅☆⋅⋆ ─── (❁´◡`❁) ─── ⋆⋅☆⋅⋆ ─── ✦
</p>

---

## 5.1.1 Current Build Snapshot

<p align="center">
  Cheese v4 complete robot
</p>

<p align="center">
  <em>Current Cheese v4 configuration documented by this Bill of Materials.</em>
</p>

<div align="center">

| Build Property | Current Cheese v4 |
| :--- | :--- |
| **Main controller** | LEGO MINDSTORMS EV3 Intelligent Brick |
| **Power source** | EV3 Rechargeable Battery |
| **Drive motor** | 1 EV3 Large Servo Motor |
| **Steering motor** | 1 EV3 Medium Servo Motor |
| **Ultrasonic sensors** | 3 |
| **Color sensor** | 1 EV3 Color Sensor |
| **Vision sensor** | 1 HuskyLens K210 |
| **Vision bridge** | 1 Arduino Nano |
| **Steering architecture** | Front Ackermann steering |
| **Drive architecture** | Rear-wheel propulsion |
| **Measured mass** | **666 g** |
| **Auxiliary lights** | Not used in v4 |

</div>

The current version was designed around a simple BOM principle:

<p align="center">
  <strong>
    Keep Necessary Components → Improve Their Placement → Remove Unnecessary Structure
  </strong>
</p>

---

## 5.1.2 Complete Cheese v4 Mega-BOM

This table is the main component inventory for Cheese v4.

The first column uses external reference photographs so another team can identify
the type of component being discussed.

> **Important:** for structural categories such as liftarms, pins, axles and
> bushings, the internet photograph represents the **component family**.
> Cheese uses multiple lengths and variants, so the photograph does not imply
> that every structural piece is the exact same model.

<div align="center">

| Reference Image | Component | Qty. | Model / Reference | Function in Cheese | Connection / Location | Source |
| :---: | :--- | :---: | :--- | :--- | :--- | :---: |
| <a href="https://www.bricklink.com/v2/catalog/catalogitem.page?S=45500-1">EV3 Intelligent Brick</a> | **EV3 Intelligent Brick** | 1 | LEGO 45500 | Main robot controller | Center chassis | [BrickLink](https://www.bricklink.com/v2/catalog/catalogitem.page?S=45500-1) |
| <a href="https://www.bricklink.com/v2/catalog/catalogitem.page?S=45501-1">EV3 Rechargeable Battery</a> | **EV3 Rechargeable Battery** | 1 | LEGO 45501 | Main power supply | EV3 Brick | [BrickLink](https://www.bricklink.com/v2/catalog/catalogitem.page?S=45501-1) |
| <a href="https://www.bricklink.com/v2/catalog/catalogitem.page?S=45502-1">EV3 Large Servo Motor</a> | **EV3 Large Servo Motor** | 1 | LEGO 45502 | Rear propulsion | Output B | [BrickLink](https://www.bricklink.com/v2/catalog/catalogitem.page?S=45502-1) |
| <a href="https://www.bricklink.com/v2/catalog/catalogitem.page?S=45503-1">EV3 Medium Servo Motor</a> | **EV3 Medium Servo Motor** | 1 | LEGO 45503 | Steering actuation | Output A | [BrickLink](https://www.bricklink.com/v2/catalog/catalogitem.page?S=45503-1) |
| <a href="https://www.bricklink.com/v2/catalog/catalogitem.page?S=45504-1">EV3 Ultrasonic Sensor</a> | **EV3 Ultrasonic Sensor** | 3 | LEGO 45504 | Left, right and front distance sensing | Inputs 1–3 | [BrickLink](https://www.bricklink.com/v2/catalog/catalogitem.page?S=45504-1) |
| <a href="https://www.bricklink.com/v2/catalog/catalogitem.page?S=45506-1">EV3 Color Sensor</a> | **EV3 Color Sensor** | 1 | LEGO 45506 | Floor-color and curve-event detection | Input 4 | [BrickLink](https://www.bricklink.com/v2/catalog/catalogitem.page?S=45506-1) |
| <a href="https://www.dfrobot.com/product-1989.html">HuskyLens</a> | **HuskyLens AI Vision Sensor** | 1 | SEN0305 / K210 family | Colored-pillar recognition | I²C → Nano | [DFRobot](https://www.dfrobot.com/product-1989.html) |
| <a href="https://store.arduino.cc/products/arduino-nano">Arduino Nano</a> | **Arduino Nano** | 1 | ATmega328 / A000005 | Vision communication bridge | USB → EV3 | [Arduino](https://store.arduino.cc/products/arduino-nano) |
| <a href="https://www.bricklink.com/v2/catalog/catalogitem.page?P=39367pb01">SPIKE wheel</a> | **Front SPIKE wheel assemblies** | 2 | Technic Wheel 56 × 14 family | Front steering contact | Front axle | [BrickLink](https://www.bricklink.com/v2/catalog/catalogitem.page?P=39367pb01) |
| <a href="https://www.bricklink.com/v2/catalog/catalogitem.page?P=56145c01">Technic rear wheel</a> | **Rear drive wheel assemblies** | 2 | EV3 / Technic wheel family | Propulsion contact | Rear axle | [BrickLink](https://www.bricklink.com/v2/catalog/catalogitem.page?P=56145c01) |
| <a href="https://www.bricklink.com/v2/catalog/catalogitem.page?P=64781">Technic gear rack</a> | **Ackermann steering linkage** | 1 system | Technic steering system | Converts steering-motor movement into front-wheel angle | Front chassis | [BrickLink reference](https://www.bricklink.com/v2/catalog/catalogitem.page?P=64781) |
| <a href="https://www.bricklink.com/v2/catalog/catalogitem.page?P=3705">Technic axle</a> | **Rear drive axle system** | 1 system | Technic axle drivetrain | Transfers propulsion to rear wheels | Rear chassis | [BrickLink reference](https://www.bricklink.com/v2/catalog/catalogitem.page?P=3705) |
| <a href="https://www.bricklink.com/v2/catalog/catalogitem.page?P=32524">Technic liftarm</a> | **Technic liftarms / beams** | ~50 | Assorted lengths | Main chassis and supports | Throughout robot | [BrickLink reference](https://www.bricklink.com/v2/catalog/catalogitem.page?P=32524) |
| <a href="https://www.bricklink.com/v2/catalog/catalogitem.page?P=2780">Technic pin</a> | **Technic pins** | ~70 | Assorted | Structural connections | Throughout robot | [BrickLink reference](https://www.bricklink.com/v2/catalog/catalogitem.page?P=2780) |
| <a href="https://www.bricklink.com/v2/catalog/catalogitem.page?P=3705">Technic axle</a> | **Technic axles** | 9 | Assorted lengths | Steering, drivetrain and wheels | Mechanical systems | [BrickLink reference](https://www.bricklink.com/v2/catalog/catalogitem.page?P=3705) |
| <a href="https://www.bricklink.com/v2/catalog/catalogitem.page?P=3713">Technic bush</a> | **Bushings / spacers** | 7 | Technic bush family | Axle spacing and alignment | Mechanical systems | [BrickLink reference](https://www.bricklink.com/v2/catalog/catalogitem.page?P=3713) |
| <a href="https://www.bricklink.com/v2/catalog/catalogitem.page?S=45514-1">EV3 cable pack</a> | **EV3 motor cables** | 2 | EV3 cable family | EV3-to-motor connection | Outputs A/B | [BrickLink](https://www.bricklink.com/v2/catalog/catalogitem.page?S=45514-1) |
| <a href="https://www.bricklink.com/v2/catalog/catalogitem.page?S=45514-1">EV3 cable pack</a> | **EV3 sensor cables** | 4 | EV3 cable family | EV3-to-sensor connection | Inputs 1–4 | [BrickLink](https://www.bricklink.com/v2/catalog/catalogitem.page?S=45514-1) |
| <a href="https://commons.wikimedia.org/wiki/File:Usb_connectors.JPG">USB connectors</a> | **USB Type-A → Mini-B cable** | 1 | Short USB data cable | Nano ↔ EV3 communication | EV3 USB | [Wikimedia Commons](https://commons.wikimedia.org/wiki/File:Usb_connectors.JPG) |
| <a href="https://www.dfrobot.com/product-1581.html">Jumper wires</a> | **HuskyLens / Nano I²C conductors** | 4 | VCC / GND / SDA / SCL | Camera power and data | HuskyLens ↔ Nano | [DFRobot cable reference](https://www.dfrobot.com/product-1581.html) |
| <a href="https://www.bricklink.com/v2/catalog/catalogitem.page?P=32524">Technic reinforcement beam</a> | **Minor reinforcement pieces** | As needed | Assorted Technic | Local structural reinforcement | Chassis | [BrickLink](https://www.bricklink.com/v2/catalog/catalogitem.page?P=32524) |
| <a href="https://commons.wikimedia.org/wiki/File:FF_Jumper_Wires.jpg">Wire reference</a> | **Cable retention / routing pieces** | As needed | Support / routing system | Keeps wiring away from moving mechanisms | Chassis | [Wikimedia Commons](https://commons.wikimedia.org/wiki/File:FF_Jumper_Wires.jpg) |

</div>

Every row now contains a visual reference.

External photographs identify the components while the following subsections show
how the important systems are used in the actual Cheese v4 robot.

---

## 5.1.3 Main Controller and Power System

### EV3 Intelligent Brick

<p align="center">
  <a href="https://www.bricklink.com/v2/catalog/catalogitem.page?S=45500-1">
    EV3 Intelligent Brick
  </a>
</p>

<p align="center">
  <em>External component reference — LEGO EV3 Intelligent Brick 45500.</em>
</p>

The EV3 Brick is the main controller of Cheese.

It:

- executes the autonomous program,
- reads EV3 sensors,
- controls both motors,
- handles Open Challenge navigation,
- and receives processed vision information through the Nano bridge.

<p align="center">
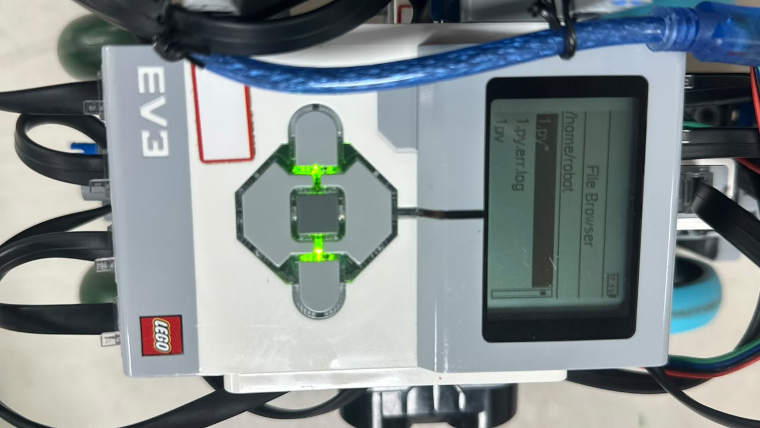
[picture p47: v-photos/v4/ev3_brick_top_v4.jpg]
EV3 Brick installed on Cheese v4
  
</p>

The Brick is mounted relatively low and flat with its screen facing upward.

---

### EV3 Rechargeable Battery

<p align="center">
  <a href="https://www.bricklink.com/v2/catalog/catalogitem.page?S=45501-1">
    EV3 Rechargeable Battery
  </a>
</p>

<p align="center">
  <em>External component reference — EV3 Rechargeable DC Battery 45501.</em>
</p>

The rechargeable EV3 battery provides the main power supply.

<p align="center">
  Cheese v4 battery access
</p>

Battery condition matters during testing because changes in motor response can
affect steering, driving and recovery behavior.

---

## 5.1.4 Motors and Drivetrain

### EV3 Large Servo Motor

<p align="center">
  <a href="https://www.bricklink.com/v2/catalog/catalogitem.page?S=45502-1">
    EV3 Large Servo Motor
  </a>
</p>

**Quantity:** 1  
**Connection:** Output B  
**Function:** propulsion

<p align="center">
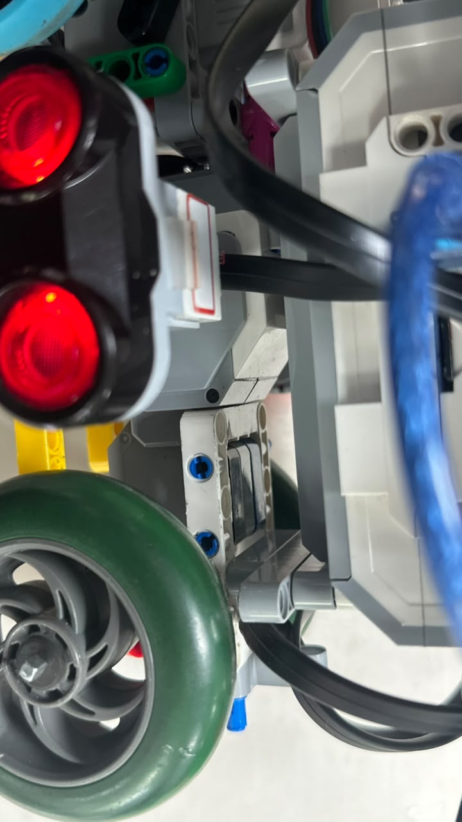
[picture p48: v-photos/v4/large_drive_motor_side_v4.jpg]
Large Motor installed on Cheese v4
  
</p>

The Large Motor is mounted horizontally in v4.

<p align="center">
  <strong>
    Large Motor → Rear Drivetrain → Rear Wheels
  </strong>
</p>

---

### EV3 Medium Servo Motor

<p align="center">
  <a href="https://www.bricklink.com/v2/catalog/catalogitem.page?S=45503-1">
    EV3 Medium Servo Motor
  </a>
</p>

**Quantity:** 1  
**Connection:** Output A  
**Function:** steering actuator

<p align="center">
  Medium Motor installed on Cheese v4
</p>

The Medium Motor controls the front steering system.

<p align="center">
  <strong>
    Medium Motor → Steering Linkage → Front Wheel Angle
  </strong>
</p>

---

## 5.1.5 Front and Rear Wheels

### Front SPIKE Wheel Assemblies

<p align="center">
  <a href="https://www.bricklink.com/v2/catalog/catalogitem.page?P=39367pb01">
    LEGO SPIKE 56 x 14 wheel
  </a>
</p>

<p align="center">
  <em>Online reference for the 56 × 14 Technic / SPIKE wheel family.</em>
</p>

Cheese uses two SPIKE-style wheel assemblies at the front.

<p align="center">
  Cheese v4 front SPIKE wheels
</p>

They provide the front contact points used by the Ackermann steering system.

---

### Rear Drive Wheels

<p align="center">
  <a href="https://www.bricklink.com/v2/catalog/catalogitem.page?P=56145c01">
    LEGO Technic wheel assembly
  </a>
</p>

<p align="center">
  <em>Representative EV3 / Technic wheel-family reference.</em>
</p>

<p align="center">
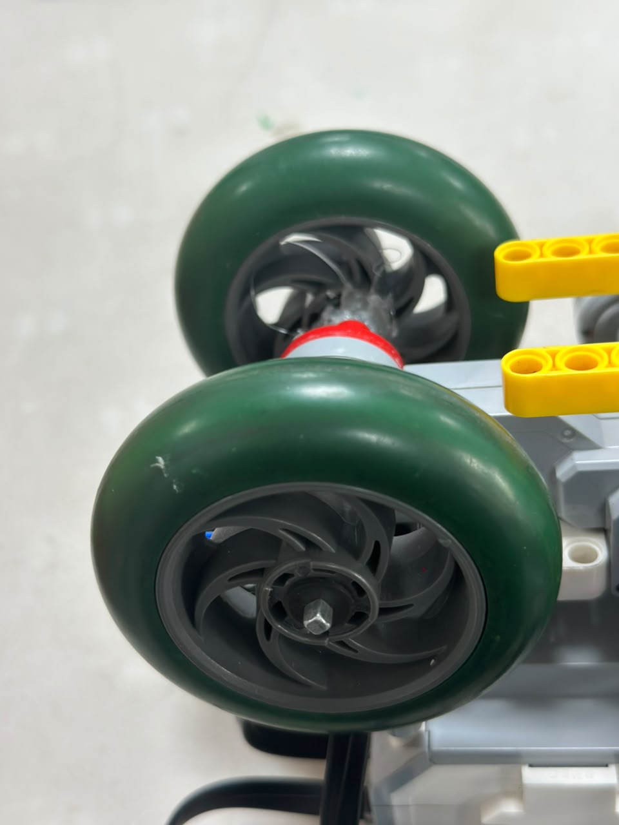
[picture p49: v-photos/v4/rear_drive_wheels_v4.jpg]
Cheese rear drive wheels
  
</p>

The rear wheels are the propulsion contact points.

---

## 5.1.6 Ackermann Steering Components

Cheese does not use tank steering.

The Medium Motor controls a LEGO Technic linkage that turns the two front wheels.

<p align="center">
  <a href="https://www.bricklink.com/v2/catalog/catalogitem.page?P=64781">
    Technic steering rack reference
  </a>
</p>

<p align="center">
  <em>
    Representative online reference for a Technic steering component.
    Cheese's steering assembly itself is made from several Technic elements.
  </em>
</p>

<p align="center">
  Cheese v4 Ackermann steering
</p>

Changing the steering geometry can change:

- maximum steering angle,
- inside-wheel angle,
- outside-wheel angle,
- turning radius,
- and curve behavior.

For that reason, steering geometry is considered part of the reproducible BOM.

---

## 5.1.7 Ultrasonic Sensor System

<p align="center">
  <a href="https://www.bricklink.com/v2/catalog/catalogitem.page?S=45504-1">
    EV3 Ultrasonic Sensor
  </a>
</p>

<p align="center">
  <em>LEGO EV3 Ultrasonic Sensor 45504.</em>
</p>

Cheese uses three ultrasonic sensors.

<div align="center">

| Position | Port | Purpose |
| :--- | :---: | :--- |
| **Left** | Input 1 | Left-wall distance |
| **Right** | Input 2 | Right-wall distance |
| **Front** | Input 3 | Forward clearance and recovery safety |

</div>

<p align="center">
  Cheese v4 side ultrasonic sensors
</p>

<p align="center">
  Cheese front ultrasonic sensor
</p>

The physical position of the sensors is critical because:

<p align="center">
  <strong>
    Sensor Position → Distance Measurement → Controller Error → Steering Correction
  </strong>
</p>

---

## 5.1.8 Color Sensor

<p align="center">
  <a href="https://www.bricklink.com/v2/catalog/catalogitem.page?S=45506-1">
    EV3 Color Sensor
  </a>
</p>

<p align="center">
  <em>LEGO EV3 Color Sensor 45506.</em>
</p>

**Quantity:** 1  
**Connection:** Input 4  
**Orientation:** floor-facing

The sensor detects floor-color events used for Open Challenge progress and curve counting.

<p align="center">
  Cheese v4 Color Sensor
</p>

The sensor's height above the mat is important.

<p align="center">
  Cheese Color Sensor floor gap
</p>

A previous light-blocking cover was removed because it could contact the floor.
The current solution keeps the sensor low while preserving physical clearance.

---

## 5.1.9 HuskyLens Vision Sensor

<p align="center">
  <a href="https://www.dfrobot.com/product-1989.html">
    HuskyLens AI Vision Sensor
  </a>
</p>

<p align="center">
  <em>HuskyLens external product reference — DFRobot.</em>
</p>

The HuskyLens provides obstacle color recognition for the Obstacle Challenge.

Current training:

<div align="center">

| Pillar | HuskyLens ID | Required Passing Side |
| :--- | :---: | :---: |
| **Green** | **ID 1** | **Left** |
| **Red** | **ID 2** | **Right** |

</div>

<p align="center">
  HuskyLens installed on Cheese
</p>

<p align="center">
  Cheese HuskyLens side angle
</p>

The camera angle affects the point at which a pillar enters the field of view,
making camera geometry a critical reproducibility variable.

---

## 5.1.10 Arduino Nano

<p align="center">
  <a href="https://store.arduino.cc/products/arduino-nano">
    Arduino Nano
  </a>
</p>

<p align="center">
  <em>Arduino Nano external product reference — Arduino.</em>
</p>

The Nano acts as a communication bridge rather than the main robot controller.

<div align="center">

| Property | Reference |
| :--- | :--- |
| **Microcontroller** | ATmega328 |
| **Operating voltage** | 5 V |
| **USB connector** | Mini-B |
| **I²C SDA** | A4 |
| **I²C SCL** | A5 |

</div>

The architecture is:

<p align="center">
  <strong>
    HuskyLens → I²C → Arduino Nano → USB Serial → EV3
  </strong>
</p>

<p align="center">
  Arduino Nano on Cheese
</p>

---

## 5.1.11 Cable and Communication Components

### EV3 Cable Family

<p align="center">
  <a href="https://www.bricklink.com/v2/catalog/catalogitem.page?S=45514-1">
    LEGO EV3 Cable Pack
  </a>
</p>

<div align="center">

| Cable | Qty. | Purpose |
| :--- | :---: | :--- |
| **EV3 motor cable** | 2 | Motors → EV3 outputs |
| **EV3 sensor cable** | 4 | Sensors → EV3 inputs |

</div>

---

### USB Type-A → Mini-B

<p align="center">
  <a href="https://commons.wikimedia.org/wiki/File:Usb_connectors.JPG">
    USB connector types
  </a>
</p>

<p align="center">
  <em>
    External USB connector reference — Wikimedia Commons.
  </em>
</p>

Cheese uses a short Type-A to Mini-B USB cable between the EV3 host connection
and Arduino Nano.

<p align="center">
  EV3 to Nano USB connection
</p>

---

### I²C Conductors

<p align="center">
  <a href="https://www.dfrobot.com/product-1581.html">
    Jumper wire reference
  </a>
</p>

<p align="center">
  <em>
    Representative jumper-wire image. DFRobot's Gravity 4-pin I²C/UART
    cable is linked as the technical cable reference.
  </em>
</p>

<div align="center">

| Signal | Nano Connection |
| :--- | :--- |
| **VCC / +** | 5V |
| **GND / −** | GND |
| **SDA / T** | A4 |
| **SCL / R** | A5 |

</div>

<p align="center">
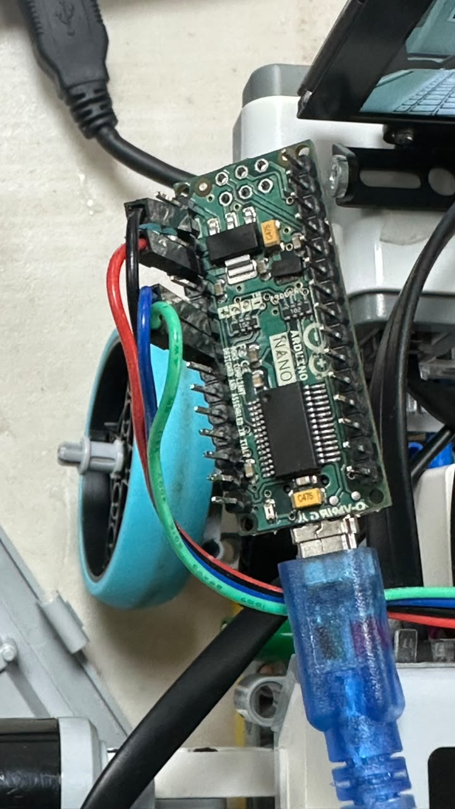
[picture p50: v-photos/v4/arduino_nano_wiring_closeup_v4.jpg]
Cheese Nano wiring
  
</p>

---

## 5.1.12 LEGO Technic Structural Inventory

Cheese uses several different Technic pieces.

The online images below identify the component families.

### Liftarms / Beams

<p align="center">
  <a href="https://www.bricklink.com/v2/catalog/catalogitem.page?P=32524">
    Technic liftarm
  </a>
</p>

**Approximate quantity:** ~50

These form:

- the chassis,
- motor supports,
- side structure,
- steering support,
- and sensor-support structure.

---

### Technic Pins

<p align="center">
  <a href="https://www.bricklink.com/v2/catalog/catalogitem.page?P=2780">
    Technic friction pin
  </a>
</p>

**Approximate quantity:** ~70

Pins connect the Technic structure.

The exact pin colors are not important when the mechanical behavior is equivalent.

---

### Technic Axles

<p align="center">
  <a href="https://www.bricklink.com/v2/catalog/catalogitem.page?P=3705">
    Technic axle
  </a>
</p>

**Approximate total:** 9

Cheese uses several axle lengths.

They are used in:

- steering,
- wheel support,
- propulsion,
- and mechanical linkage.

---

### Bushings and Spacers

<p align="center">
  <a href="https://www.bricklink.com/v2/catalog/catalogitem.page?P=3713">
    Technic bush
  </a>
</p>

**Approximate quantity:** 7

Bushings and spacers maintain axle position and mechanical alignment.

---

<div align="center">

| Structural Category | Approx. Quantity | Main Use |
| :--- | :---: | :--- |
| **Liftarms / beams** | ~50 | Chassis and supports |
| **Pins** | ~70 | Structural connections |
| **Axles** | 9 | Steering, drivetrain and wheels |
| **Bushings / spacers** | 7 | Alignment and spacing |
| **Minor reinforcement** | As needed | Local rigidity |

</div>

---

## 5.1.13 Port and Connection Map

The current software expects the following physical layout.

<div align="center">

| Component | Connection | Role |
| :--- | :---: | :--- |
| **Medium Steering Motor** | Output A | Steering |
| **Large Drive Motor** | Output B | Propulsion |
| **Left Ultrasonic Sensor** | Input 1 | Left-wall distance |
| **Right Ultrasonic Sensor** | Input 2 | Right-wall distance |
| **Front Ultrasonic Sensor** | Input 3 | Front safety |
| **Color Sensor** | Input 4 | Floor-color events |
| **Arduino Nano** | EV3 USB | Vision bridge |
| **HuskyLens** | Nano I²C | Vision input |

</div>

A component connected to another port would require the program configuration
to be changed accordingly.

---

## 5.1.14 Critical vs Flexible Components

Not every BOM item has to be reproduced with exactly the same cosmetic appearance.

<div align="center">

| Component / Property | Classification | Reason |
| :--- | :---: | :--- |
| **EV3 Brick** | Critical | Main controller |
| **Large Motor** | Critical | Propulsion |
| **Medium Motor** | Critical | Steering |
| **Three Ultrasonic Sensors** | Critical | Navigation architecture |
| **Ultrasonic positions** | Critical | Affect distance measurements |
| **Color Sensor** | Critical | Floor-event detection |
| **Color Sensor height** | Critical | Changes readings |
| **HuskyLens** | Critical | Obstacle recognition |
| **Camera angle** | Critical | Changes detection timing |
| **Arduino Nano** | Critical | Vision communication |
| **Front wheel geometry** | Critical | Changes steering behavior |
| **Rear wheel geometry** | Critical | Changes propulsion behavior |
| **Ackermann linkage** | Critical | Defines turning geometry |
| **Axle placement** | Critical | Mechanical alignment |
| **Liftarm color** | Flexible | Cosmetic |
| **Pin color** | Flexible | Cosmetic when mechanically equivalent |
| **Minor reinforcement** | Semi-critical | Can vary if geometry remains unchanged |
| **Cable retention** | Flexible | Must keep wiring clear of moving parts |

</div>

---

## 5.1.15 v3 → v4 Component Transition

Cheese v4 was not built by replacing every component.

Working systems were kept while the physical architecture around them was redesigned.

<div align="center">

| Carried Over | Modified / Repositioned | Removed |
| :--- | :--- | :--- |
| EV3 Brick | EV3 orientation | Large camera structure |
| EV3 Rechargeable Battery | Large Motor orientation | Auxiliary lights |
| Large Motor | HuskyLens position | Lamp mounts |
| Medium Motor | Ultrasonic positions | External lighting support |
| Color Sensor | Color Sensor floor gap | Lighting wiring |
| Ultrasonic Sensors | Front wheel system | Upper tower pieces |
| HuskyLens | Nano USB cable | Extra liftarms |
| Arduino Nano | Cable routing | Extra pins |
| Rear wheels | Overall chassis | Extra axles |
| Useful Technic parts | Steering integration | Redundant supports |

</div>

<p align="center">
  Structural components removed between Cheese v3 and v4
</p>

<p align="center">
  Lighting system removed from Cheese v3
</p>

---

## 5.1.16 Mass Transition

The BOM transition also produced a measurable mass reduction.

<div align="center">

| Version | Mass |
| :--- | :---: |
| **Cheese v3** | **888.8 g** |
| **Cheese v4** | **666 g** |
| **Mass removed** | **222.8 g** |
| **Approximate reduction** | **25%** |

</div>

The objective was not to minimize the number of LEGO pieces at any cost.

The objective was to remove parts that no longer provided enough engineering
benefit to justify their mass or complexity.

---

## 5.1.17 Replacement Rules

<div align="center">

| Proposed Substitution | Recalibration Likely? | Reason |
| :--- | :---: | :--- |
| Same liftarm geometry in another color | No | Geometry remains the same |
| Equivalent pin in another color | No | Connection remains equivalent |
| Different cable-retention method | Usually no | Does not affect robot geometry |
| Minor additional reinforcement | Usually no | Must not shift sensors or mechanisms |
| Different Nano support method | Usually no | Must remain secure |
| Different ultrasonic position | **Yes** | Changes wall measurements |
| Different Color Sensor height | **Yes** | Changes floor reading |
| Different wheel diameter | **Yes** | Changes physical behavior |
| Different steering linkage | **Yes** | Changes turning geometry |
| Different motor type | **Yes** | Changes actuation |
| Different camera angle | **Yes** | Changes obstacle detection timing |

</div>

---

## 5.1.18 Real Robot Component Map

External photographs show what the individual parts look like.

These photographs show how those parts are integrated into Cheese.

<div align="center">

| Front | Rear |
| :---: | :---: |
|  |  |

| Top | Bottom |
| :---: | :---: |
|  |  |

</div>

This distinction matters for reproducibility:

<p align="center">
  <strong>
    Product Reference = What the Component Is<br>
    Robot Photograph = How Cheese Uses It
  </strong>
</p>

---
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

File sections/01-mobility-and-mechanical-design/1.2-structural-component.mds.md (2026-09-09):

# ᯓ★ 1.2 Structural Components ᯓ★

Structural components are the pieces that keep Cheese physically stable. They do not drive the robot like a motor, they do not detect walls like an ultrasonic sensor, and they do not run code like the EV3 Brick. However, they decide whether all of those systems stay in the correct position while the robot moves, turns, vibrates, and reacts to the track.

For a beginner, the easiest way to understand this section is this: the structure is the robot’s skeleton. If the skeleton is weak, the robot bends or falls apart. If the skeleton is too heavy, the robot becomes harder to move and harder to control. Cheese v4 was designed around finding the balance between **enough structure to stay reliable** and **less unnecessary structure to become lighter and cleaner**.

In Cheese v3, the structure worked, but it carried extra height, extra pieces, longer cables, and a larger camera support. In Cheese v4, we reduced the robot mass from **888 g to 666 g** by removing pieces that did not directly support movement, stability, sensor placement, wiring, or protection.

<div align="center">

| Structural Component | What It Does | Main Weakness | v4 Design Response |
| :--- | :--- | :--- | :--- |
| **Liftarms / beams** | Form the main chassis and hold every component in position. | Add weight when used excessively. | Kept only where they supported the chassis, motors, sensors, or reinforcement. |
| **Pins** | Connect liftarms and decide whether a joint locks or pivots. | Wear down, loosen, or break after repeated testing. | Used more intentionally in important support points instead of adding them everywhere. |
| **Axles** | Transmit rotation and help keep wheels aligned. | Depend on tight bushings and correct alignment. | Kept in drivetrain and wheel areas where alignment is critical. |
| **Connectors** | Join beams and axles at different angles. | Can add complexity if overused. | Kept where they improved support, sensor mounting, or compactness. |
| **Frames / angled pieces** | Create stronger support areas and corners. | Add mass if used without a clear purpose. | Reduced in non-critical upper areas while preserving the main frame. |

</div>

This section explains what structural parts we used, why they mattered, what problems they created, and how the v4 redesign made the structure lighter and more intentional.

## ❀ 1.2.1 Component Photos and Evidence ────୨ৎ────────୨ৎ────

<p align="center">
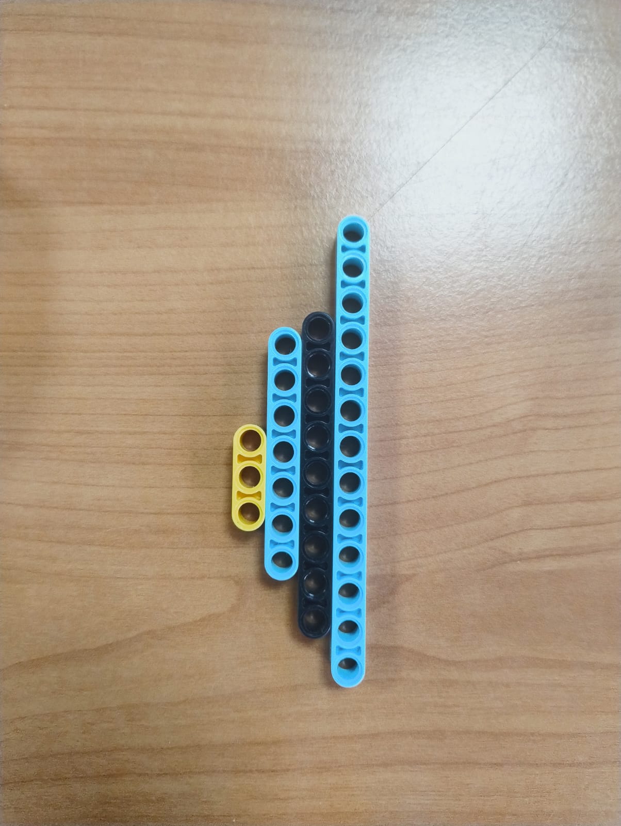
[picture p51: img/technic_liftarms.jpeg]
Technic Liftarms
  
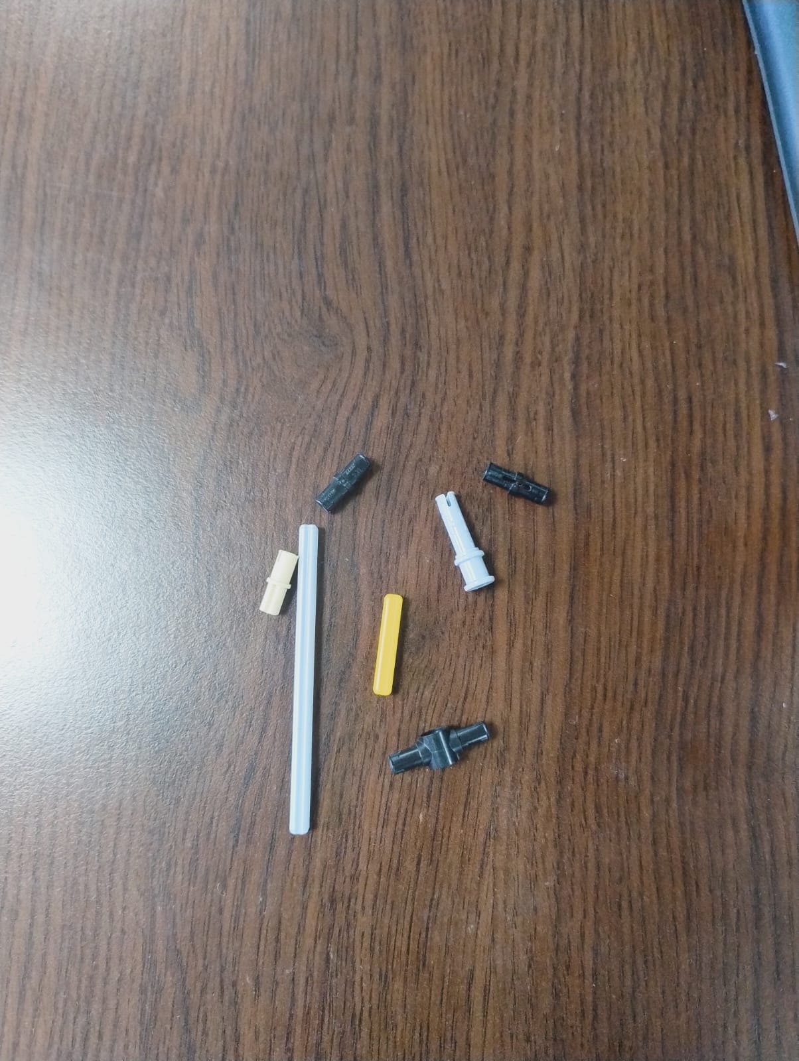
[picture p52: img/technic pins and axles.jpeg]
Technic Pins and Axles
  <br>
  <em>Left: Technic liftarms used as the main structural members of the chassis. Right: pins and axles used to connect the frame and transfer rotation through the drivetrain.</em>
</p>

<p align="center">
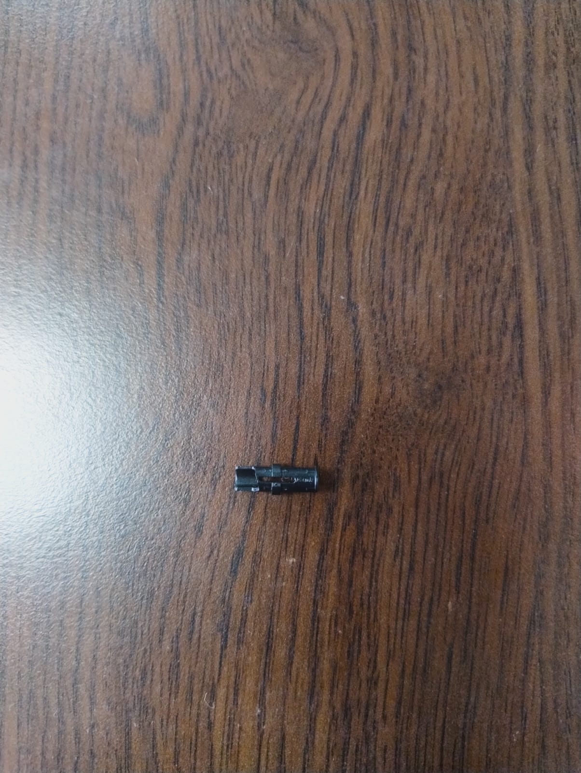
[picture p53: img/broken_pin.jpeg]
Broken Technic Pin
  <br>
  <em>Example of a broken Technic pin after repeated testing, showing why reinforced connections and better structural planning became necessary.</em>
</p>

### Cheese v3 → v4 Structural Comparison

<p align="center">
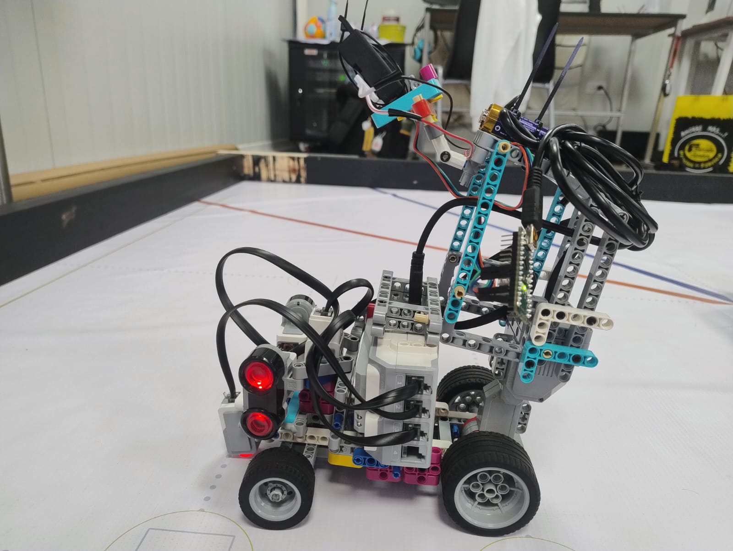
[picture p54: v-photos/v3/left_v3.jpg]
Cheese v3 left side structural view
  
  &nbsp;&nbsp;
  Cheese v4 left side structural view
</p>

<p align="center">
  <i>Side-by-side structural comparison between Cheese v3 and Cheese v4.</i>
</p>

Cheese v4 became lighter, lower, and more compact than v3. The redesign removed unnecessary upper structure, simplified the chassis, and improved the overall component layout while preserving the support needed for the drivetrain, steering system, sensors, and controller.

The transition from approximately **888 g in v3 to 666 g in v4** represents a reduction of about **222 g**, showing how structural simplification became one of the main engineering decisions behind the current version.

<p align="center">
  Cheese v4 top structural view
  Cheese v4 bottom structural view
</p>

<p align="center">
  <em>Top and bottom views of Cheese v4 showing the simplified structure and the remaining support points for the chassis, motors, sensors, and wiring.</em>
</p>

These photos are included as structural evidence. The liftarms, pins, and axles show the basic LEGO Technic parts used to build Cheese. The broken pin shows a real failure point from testing. The v3-to-v4 comparison and v4 structure photos show how the robot became lighter, cleaner, and more intentional after removing unnecessary pieces.

</div>

## ❀ 1.2.2 v3 to v4 Structural Simplification ────୨ৎ────────୨ৎ────

The most important structural change from v3 to v4 was simplification. Cheese v3 had extra upper structure, a larger camera support, longer cable paths, and structural pieces that made the robot taller and heavier than necessary. Cheese v4 kept the important support points but removed pieces that did not clearly improve performance.

<div align="center">

| v3 Problem | v4 Change | Engineering Reason |
| :--- | :--- | :--- |
| **Extra camera support structure** | Removed and simplified the camera mount. | Reduced height, mass, and unnecessary upper structure. |
| **Too much structural clutter** | Removed non-essential beams and supports. | Made the robot easier to inspect and modify. |
| **Long cable loops** | Shortened and cleaned cable routing. | Reduced clutter and made debugging easier. |
| **Heavier frame** | Reduced mass from **888 g to 666 g**. | Lower mass reduces load on motors, pins, beams, and connectors. |
| **Higher layout** | Lowered the structure and sensor layout. | Helped make the robot more compact and less top-heavy. |
| **Useful sensor support** | Kept the main sensor mounting points. | Preserved the functions needed for navigation and detection. |

</div>

The removed parts were not taken out randomly. Each part was judged by one question:

<p align="center">
  <strong>Does this piece directly help support, alignment, reinforcement, sensor position, wiring, or movement reliability?</strong>
</p>

If the answer was yes, the piece stayed. If the piece only added height, mass, or clutter, it was removed or simplified.

---

## ❀ 1.2.3 Structural Components Kept in v4 ────୨ৎ────────୨ৎ────

Cheese v4 still needed a strong structure. We did not remove the main chassis, steering support, drive support, wheel alignment parts, or sensor mounting points. The goal was not to make the robot fragile; the goal was to remove excess structure while keeping the support needed for reliable movement.

<div align="center">

| LEGO Technic Piece | Approximate Use | Why It Was Kept |
| :--- | :---: | :--- |
| **Technic Beam 15L** | 2 | Used for long chassis support and main frame length. |
| **Technic Beam 11L** | Several | Used to connect larger chassis sections. |
| **Technic Beam 7L** | Several | Used for medium support areas and local reinforcement. |
| **Technic Beam 5L** | Several | Used for compact supports and small frame sections. |
| **Technic Beam 3L** | Several | Used for short connections and tight areas. |
| **Technic Thin Beam 5L** | Several | Used where a thinner support was enough. |
| **Technic L-Shape Beam 3×5** | Several | Used to create stronger corners and support angles. |
| **Technic Angled Beam / Bent Liftarm** | Several | Used where straight beams could not create the needed geometry. |
| **Technic Frame** | 1–2 | Used to support larger rigid sections. |
| **Technic Brick with Holes** | Several | Used to connect stud-based structure with Technic connections. |
| **Technic Axles** | Several | Used for wheel alignment and rotating connections. |
| **Technic Pin with Friction** | Many | Used to hold beams tightly together. |
| **Technic Pin 3L with Friction** | Several | Used for stronger multi-layer connections. |
| **Technic Axle Pin** | Several | Used where a connection needed both pin and axle geometry. |
| **Technic Axle Pin 3L with Friction** | Several | Used for stronger mixed connections. |
| **Technic Bush / Half Bush** | Several | Used to stop axles and wheels from sliding. |
| **Technic Axle Connector** | Several | Used to extend or redirect axle connections. |
| **Technic Axle and Pin Connector** | Several | Used to connect rotating and fixed structures. |
| **Technic Perpendicular Connector** | Several | Used to make 90-degree structural joints. |
| **Technic Pin Connector Round** | Several | Used in compact linkage or support areas. |

</div>

These pieces were kept because they had a clear purpose. Some supported the chassis, some held motors, some helped keep sensors in place, and others allowed axles and wheels to stay aligned. In v4, each remaining structural piece needed to justify its position.

## ❀ 1.2.4 Technic Liftarms ────୨ৎ────────୨ৎ────

<p align="center">
  
  
  
</p>

<p align="center">
  <em>Liftarms are the main structural bones of Cheese. They decide where motors, sensors, wheels, cables, and the EV3 Brick stay during movement.</em>
</p>

---

### ❀ What Liftarms Are ────୨ৎ────────୨ৎ────

Liftarms are LEGO Technic beams with holes that allow pins, axles, and connectors to pass through them. On Cheese, they form the main frame of the robot. They do not move the robot by themselves, but they hold the parts that do.

For a beginner, liftarms are like the **bones of the robot**. They decide the robot’s shape, length, width, height, and support points. If the liftarms are placed badly, the robot can become weak, heavy, difficult to repair, or unstable during movement.

<p align="center">
  Technic liftarms used in Cheese
</p>

<p align="center">
  <em>Technic liftarms used as structural beams for the robot frame.</em>
</p>

---

### ❀ Why We Build With Liftarms ────୨ৎ────────୨ৎ────

Liftarms are useful because they are stiff, modular, easy to connect, and easy to rebuild. Their holes follow the LEGO Technic grid, which makes it possible to place motors, wheels, and sensors in repeatable positions.

<div align="center">

| Liftarm Advantage | How It Helps Cheese |
| :--- | :--- |
| **Rigid frame support** | Helps the robot keep its shape while driving, turning, and vibrating. |
| **Standard hole spacing** | Makes sensor and motor placement easier to repeat and adjust. |
| **Fast rebuilding** | Allows the team to test changes quickly between runs. |
| **Many sizes available** | Helps create long chassis supports, small reinforcements, and compact mounts. |
| **Strong mounting points** | Holds motors, sensors, EV3 Brick, lights, and cables in fixed positions. |

</div>

Liftarms gave Cheese a structure that could be changed many times during testing. This mattered because the robot went through several versions before reaching the v4 layout.

---

### ❀ Why Liftarm Rigidity Matters for Software ────୨ৎ────────୨ৎ────

The structure does not only affect the mechanical side of Cheese. It also affects the software.

Cheese uses sensor readings to decide how to steer. If the frame bends or shakes too much, the sensors can move slightly. When that happens, the robot may think it is drifting toward a wall even if the real problem is that the sensor mount moved.

<p align="center">
  <strong>Stable structure → stable sensor position → reliable readings → better steering decisions</strong>
</p>

This is why liftarms matter for the robot’s control system. The code can only react correctly if the sensors are physically stable.

<div align="center">

| Structural Issue | Software Effect |
| :--- | :--- |
| **Frame flex** | Ultrasonic sensors may give inconsistent wall readings. |
| **Loose sensor mount** | Color or camera readings may change because the sensor angle changes. |
| **Weak motor support** | Steering or drive movement can become less predictable. |
| **Too much vibration** | The robot may overcorrect because readings become noisy. |

</div>

A strong structure helps the code make better decisions because the sensors stay where they are supposed to be.

---

### ❀ Liftarm Trade-Off: Strength vs. Weight ────୨ৎ────────୨ৎ────

<p align="center">
  
  
  
</p>

<p align="center">
  <strong>Liftarms made Cheese strong, but too many liftarms made Cheese heavier than necessary.</strong>
</p>

Liftarms add weight when they are used excessively. One liftarm does not weigh much by itself, but many liftarms together can make the robot heavier, taller, and harder to inspect.

In **v3**, some liftarms were necessary, but others only added extra height, bulk, or support around areas that did not directly improve performance. In **v4**, we removed or reduced liftarms that only added unnecessary upper structure, especially around the camera mount. However, we kept the liftarms that supported the main chassis, drive system, steering system, and sensor mounts.

---

<div align="center">

| ❀ Design Question | ✦ Engineering Answer |
| :--- | :--- |
| **Do we need this beam for support?** | If yes, it stays. |
| **Does it hold a motor, sensor, wheel, or chassis section?** | If yes, it is part of the main structure. |
| **Does it only add height or clutter?** | If yes, it can be removed or simplified. |
| **Would removing it make the robot weak?** | If yes, we keep reinforcement in that area. |
| **Would removing it make the robot lighter without losing function?** | If yes, it supports the v4 redesign goal. |

</div>

---

<p align="center">
  
</p>

<p align="center">
  <strong>A stronger robot is not always the robot with the most beams.</strong><br>
  A stronger robot is the one where each beam has a clear purpose.
</p>

---

### ❀ v4 Liftarm Decision Map ────୨ৎ────────୨ৎ────

<div align="center">

| ✅ Kept in v4 | 🧀 Why It Stayed | ❌ Removed or Reduced | 🧠 Why It Changed |
| :--- | :--- | :--- | :--- |
| **Main chassis beams** | Hold the robot’s main body together. | **Extra upper camera support beams** | Added height and mass without being essential. |
| **Motor support beams** | Keep the drive and steering motors fixed. | **Non-critical upper structure** | Made the robot taller and harder to inspect. |
| **Sensor mount beams** | Keep sensors facing the correct direction. | **Excess reinforcement around low-risk areas** | Added weight without improving performance. |
| **Steering support beams** | Keep steering geometry stable. | **Bulky liftarms near the camera mount** | Made the structure heavier and more cluttered. |
| **Wheel alignment supports** | Help keep wheel geometry consistent. | **Pieces that made inspection harder** | Slowed down debugging and modifications. |

</div>

---

### ❀ Why This Improved v4 ────୨ৎ────────୨ৎ────

<p align="center">
  
  
  
</p>

<div align="center">

| v4 Improvement | What Changed | Why It Matters |
| :--- | :--- | :--- |
| **Lower mass** | Fewer unnecessary beams and supports. | Less load for motors, pins, axles, and connectors. |
| **Cleaner structure** | Less visual and physical clutter. | Easier to inspect, repair, and explain. |
| **Lower layout** | Extra upper structure was removed. | Helps reduce top-heavy behavior. |
| **Better access** | Fewer pieces blocking important areas. | Faster debugging during testing. |
| **More intentional design** | Every remaining liftarm has a purpose. | Supports the engineering decision process. |

</div>

---

### ❀ Liftarms and Mechanical Stress ────୨ৎ────────୨ৎ────

The liftarm structure also affects how much stress the robot experiences. A heavier robot places more load on its frame. During turns, starts, stops, and wall corrections, that load is repeated many times.

Using the weight equation:

<p align="center">
  <strong>W = m × g</strong>
</p>

For v3:

<p align="center">
  <strong>W = 0.888 kg × 9.81 m/s² ≈ 8.71 N</strong>
</p>

For v4:

<p align="center">
  <strong>W = 0.666 kg × 9.81 m/s² ≈ 6.53 N</strong>
</p>

This means the v4 structure supports less downward force than the v3 structure. That matters because beams, pins, axles, and connectors experience less mechanical load during repeated testing.

<div align="center">

| Version | Mass | Approximate Weight Force | Structural Meaning |
| :--- | :---: | :---: | :--- |
| **v3** | 888 g | ≈ 8.71 N | More load on beams and connections. |
| **v4** | 666 g | ≈ 6.53 N | Less load and less repeated stress. |

</div>

The mass reduction does not remove the need for a strong frame, but it helps reduce the amount of force that the frame must handle.

---

### ❀ Final Liftarm Decision ────୨ৎ────────୨ৎ────

<p align="center">
  <strong>Cheese v4 became lighter and more compact while still keeping the support needed for reliable movement.</strong>
</p>

The final decision was to keep liftarms where they supported the main chassis, motors, wheels, sensors, and steering system. We removed or reduced liftarms that only added height, clutter, or unnecessary mass.

This made the v4 structure more intentional. Instead of building by adding more beams everywhere, we built by asking what each beam actually needed to do.

<p align="center">
  ✦ ─── ⋆⋅☆⋅⋆ ─── (❁´◡`❁) ─── ⋆⋅☆⋅⋆ ─── ✦
</p>

## ❀ 1.2.5 Technic Pins and Connectors ────୨ৎ────────୨ৎ────

<p align="center">
  
  
  
</p>

<p align="center">
  <em>Pins and connectors are the small parts that turn separate liftarms into one complete robot structure.</em>
</p>

---

### ❀ What Pins and Connectors Do ────୨ৎ────────୨ৎ────

Pins and connectors are what hold Cheese together. They connect liftarms, motors, sensors, cable supports, and chassis sections into one structure.

### ❀ Physical Evidence: Pins, Axles, and Connectors ────୨ৎ────────୨ৎ────

<p align="center">
  Technic pins, axles, and connector pieces used in Cheese
</p>

<p align="center">
  <em>Technic pins, axles, and connectors used to hold the robot frame together, transfer rotation, and keep moving parts aligned.</em>
</p>

This image shows the small structural pieces that make the robot possible. Even though they are not motors or sensors, they decide whether the frame stays connected, whether the wheels remain aligned, and whether the robot can survive repeated testing.

For a beginner, pins are like the small locks of the robot. Without them, the liftarms would not stay connected. Some pins create tight fixed joints, while other connectors allow special angles, corners, pivots, or compact supports.

<div align="center">

| Part | Beginner Explanation | Why It Matters on Cheese |
| :--- | :--- | :--- |
| **Friction pins** | Tight pins that hold beams firmly together. | Keep the chassis and mounts from separating during testing. |
| **3L pins** | Longer pins that connect multiple layers. | Help reinforce thicker or stacked structures. |
| **Axle pins** | Hybrid pieces that connect pin holes and axle holes. | Useful when a support must connect fixed and rotating geometry. |
| **Perpendicular connectors** | Connect beams at 90 degrees. | Help build corners, braces, and compact mounts. |
| **Round pin connectors** | Small connector bodies used in tight spaces. | Help create compact supports or linkage areas. |

</div>

Pins and connectors may look small, but they decide whether the robot stays aligned during movement. If one connection loosens, a motor, sensor, or wheel support can shift slightly, and that small movement can affect the robot’s behavior.

---

### ❀ Why We Build With Pins and Connectors ────୨ৎ────────୨ৎ────

Pins and connectors are useful because they make the robot modular. During testing, Cheese needed many rebuilds and small adjustments. Pins allowed us to change the structure quickly without permanently damaging the robot.

<div align="center">

| Benefit | How It Helped Cheese |
| :--- | :--- |
| **Fast rebuilding** | We could modify parts of the robot between tests. |
| **Adjustable structure** | Sensor mounts and supports could be moved when testing showed problems. |
| **Strong connections** | Friction pins helped keep liftarms locked together. |
| **Compact building** | Connectors helped fit supports in tight spaces. |
| **Repairability** | Damaged or loose sections could be replaced quickly. |

</div>

This mattered because Cheese changed across versions. The structure was not perfect at the beginning, so we needed parts that allowed fast testing, failure observation, and rebuilding.

---

### ❀ Main Weakness of Pins ────୨ৎ────────୨ৎ────

<p align="center">
  
  
</p>

Pins are useful, but they are also one of the weakest parts of a LEGO Technic robot. They can loosen, wear down, crack, or break after repeated testing.

<p align="center">
  Broken Technic Pin
</p>

<p align="center">
  <em>Broken pin evidence from repeated testing. This helped us understand that structural connections needed better support in critical areas.</em>
</p>

When a pin loosens, the structure can shift. When the structure shifts, the sensor angle, motor position, or wheel alignment can change. For Cheese, that matters because the robot depends on stable steering and sensor readings.

<div align="center">

| Pin Problem | Effect on the Robot |
| :--- | :--- |
| **Loose pin** | A beam or mount can move slightly. |
| **Worn pin** | The connection becomes less reliable over time. |
| **Broken pin** | A structural support can fail completely. |
| **Too many pins** | The structure becomes heavier and harder to inspect. |
| **Poorly placed pins** | The robot can look reinforced but still have weak points. |

</div>

This is why v4 focused on using pins more intentionally. We did not want to add pins everywhere. We wanted to keep reinforcement where it protected important systems.

---

### ❀ v4 Pin and Connector Decision Map ────୨ৎ────────୨ৎ────

<div align="center">

| ✅ Kept in v4 | 🧀 Why It Stayed | ❌ Reduced or Avoided | 🧠 Why It Changed |
| :--- | :--- | :--- | :--- |
| **Pins in main chassis joints** | These joints hold the robot body together. | **Pins in unnecessary upper structure** | That structure added weight without enough benefit. |
| **Pins around motor mounts** | Motors must stay fixed during movement. | **Excess pinning in non-critical areas** | Added clutter and made inspection harder. |
| **Sensor mount connectors** | Sensors need stable angles. | **Bulky connector stacks near the camera mount** | The camera mount was simplified in v4. |
| **Steering support connectors** | Steering geometry must stay aligned. | **Connectors that only added height** | Height made the robot more top-heavy. |
| **Cable support pins** | Help keep cables away from moving parts. | **Long cable loops and extra supports** | Shorter cables reduced the need for extra support. |

</div>
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

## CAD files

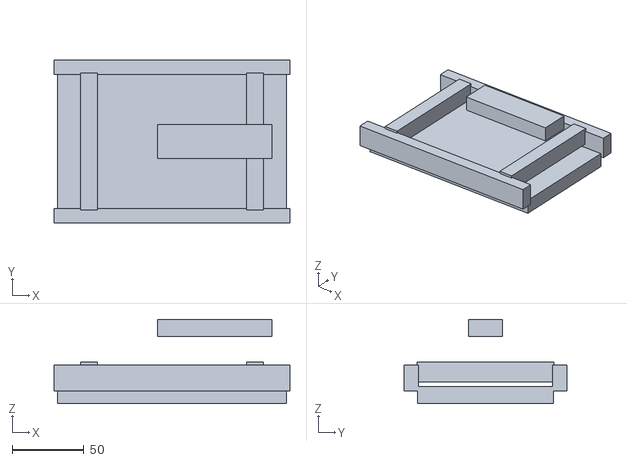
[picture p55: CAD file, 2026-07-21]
models/chassis/chassis_concept_model.stl
165.0 x 114.0 x 59.0

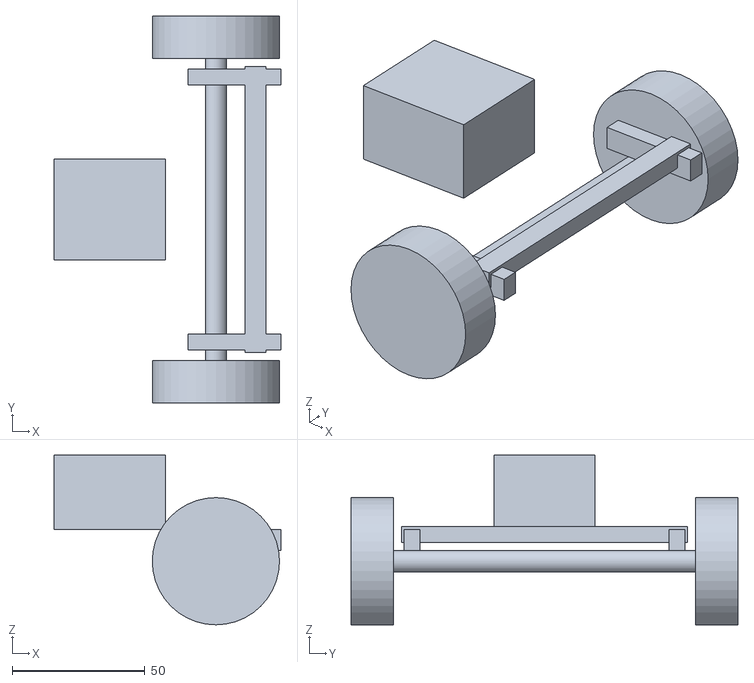
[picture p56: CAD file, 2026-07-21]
models/steering/ackermann_steering_concept.stl
85.5 x 146.0 x 64.0

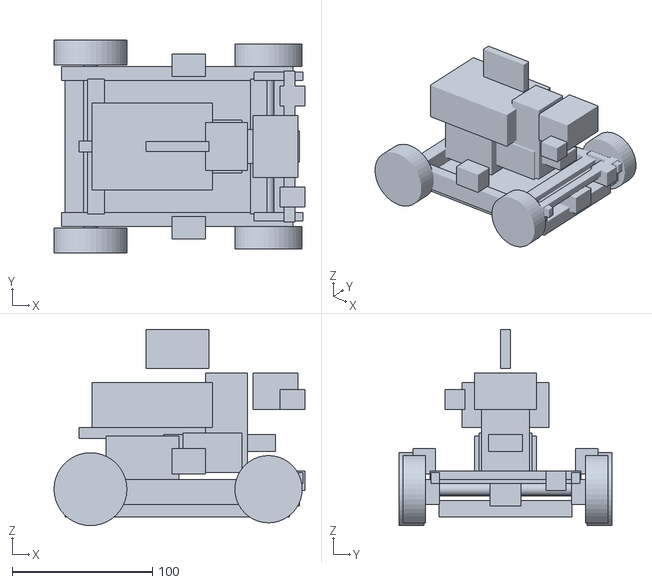
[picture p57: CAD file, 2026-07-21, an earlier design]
models/v3/cheese_v3_concept_model.stl
179.0 x 152.0 x 140.0

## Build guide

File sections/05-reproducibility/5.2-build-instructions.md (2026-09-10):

<h1 align="center">ᯓ★ 5.2 Build Instructions and Assembly Guide ᯓ★</h1>

<p align="center">
  
  
  
  
</p>

<p align="center">
  <em>
    This guide documents how the current Cheese v4 is assembled as a complete
    mechanical, sensing and control system. Real photographs of the final robot
    remain the primary construction reference.
  </em>
</p>

<p align="center">
  ✦ ─── ⋆⋅☆⋅⋆ ─── (❁´◡`❁) ─── ⋆⋅☆⋅⋆ ─── ✦
</p>

---

## 5.2.1 Building Cheese v4

Cheese v4 was not created by simply adding components to the previous robot.

The robot was rebuilt around four priorities:

<div align="center">

| Priority | Design Objective |
| :---: | :--- |
| **Compact** | Remove unnecessary upper structure and unused supports |
| **Accessible** | Keep the EV3, battery, sensors and wiring inspectable |
| **Stable** | Maintain rigid steering, drivetrain and sensor geometry |
| **Testable** | Make individual subsystems easier to verify before full runs |

</div>

The previous v3 robot weighed approximately **888.8 g**.

The current Cheese v4 weighs approximately **666 g**.

That represents a reduction of approximately:

<p align="center">
  <strong>888.8 g → 666 g = 222.8 g removed</strong>
</p>

<p align="center">
  <strong>≈ 25% reduction in total robot mass</strong>
</p>

The result is a significantly simpler physical architecture while preserving the systems required for the WRO Future Engineers challenges.

---

# 5.2.2 Visual Build Guide

The following poster summarizes the main physical systems and construction sequence of Cheese v4.

<p align="center">
  <a href="../../schemes/Cheese_V4_Build_Assembly_Guide.png">
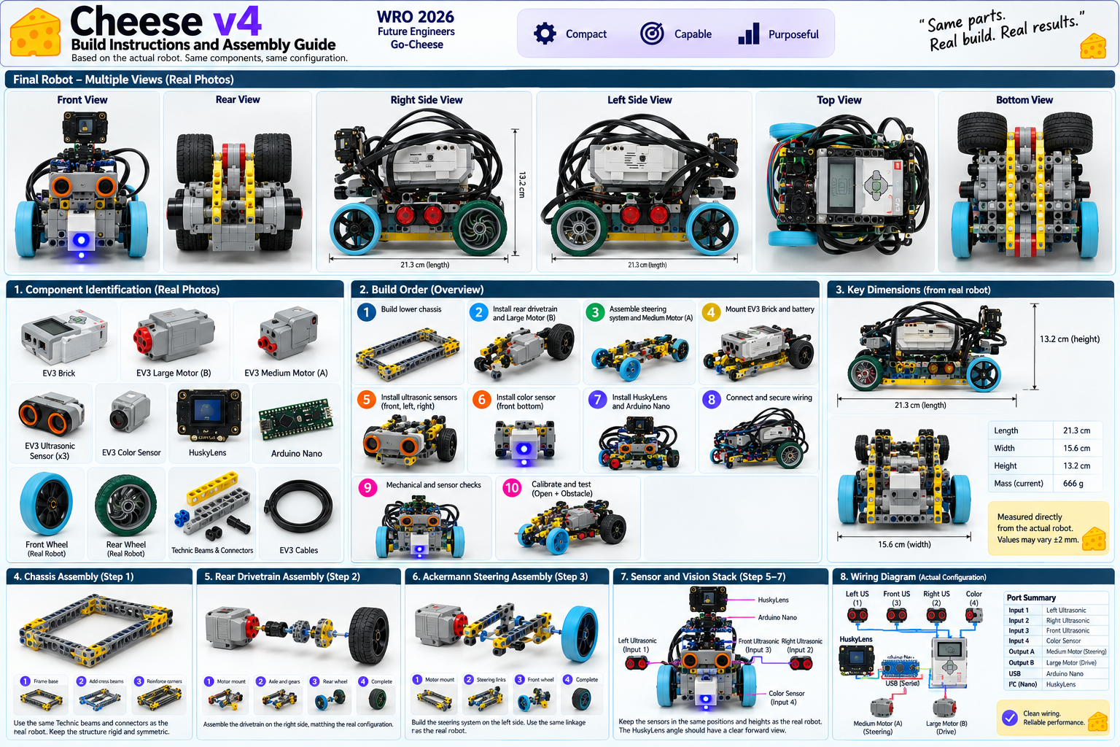
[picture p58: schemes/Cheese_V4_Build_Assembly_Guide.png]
Cheese v4 Build and Assembly Guide
    
  </a>
</p>

<p align="center">
  <em>
    Visual assembly reference created from the real Cheese v4 configuration and
    the team's photographic documentation. Click the image to open it at full size.
  </em>
</p>

> **Important:** the diagram is a visual assembly aid.  
> The real robot photographs in this repository are the definitive reference for
> exact LEGO element placement, cable routing and small structural connections.

---

# 5.2.3 Real Robot Reference Views

Before rebuilding Cheese, the final robot should be studied from several directions.

<div align="center">

| Front | Rear |
| :---: | :---: |
|  |  |
| **Front sensor / steering area** | **Rear drivetrain area** |

| Left | Right |
| :---: | :---: |
|  |  |
| **Left-side component relationship** | **Right-side component relationship** |

| Top | Bottom |
| :---: | :---: |
|  |  |
| **EV3, wiring and upper layout** | **Chassis, drivetrain and steering structure** |

</div>

No single photograph contains enough information to reproduce the robot.

Together, these views reveal:

- chassis structure,
- front/rear orientation,
- motor position,
- wheel types,
- steering geometry,
- EV3 placement,
- ultrasonic placement,
- Color Sensor position,
- HuskyLens position,
- Arduino Nano position,
- and cable routing.

---

# 5.2.4 System Layers

Cheese can be understood as a set of connected construction layers.

<div align="center">

| Layer | Main Elements | Function |
| :---: | :--- | :--- |
| **1 — Chassis** | Technic beams, pins, axles and supports | Structural foundation |
| **2 — Drive** | Large Motor, rear axle and rear wheels | Propulsion |
| **3 — Steering** | Medium Motor, Ackermann linkage and front wheels | Direction control |
| **4 — Control** | EV3 Brick and rechargeable battery | Main processing and power |
| **5 — Sensors** | 3 Ultrasonics + Color Sensor | Wall, front and floor sensing |
| **6 — Vision** | HuskyLens + Arduino Nano | Obstacle recognition and communication |

</div>

<p align="center">
  <strong>
    Structure → Motion → Control → Sensing → Vision
  </strong>
</p>

These systems should be assembled and tested progressively instead of installing everything before the first test.

---

# 5.2.5 Recommended Construction Sequence

<div align="center">

| Stage | Assembly Operation | Verification |
| :---: | :--- | :--- |
| **01** | Build lower chassis | Frame is rigid and straight |
| **02** | Install rear drivetrain | Axle rotates freely |
| **03** | Install Large Motor | Motor securely transfers drive |
| **04** | Assemble Ackermann steering | Linkage moves without binding |
| **05** | Install Medium Motor | Steering can center correctly |
| **06** | Install wheels | All wheels have correct clearance |
| **07** | Mount EV3 + battery | Controller is stable and accessible |
| **08** | Mount Ultrasonics | Sensors maintain intended orientation |
| **09** | Mount Color Sensor | Correct floor clearance |
| **10** | Mount HuskyLens + Nano | Vision direction remains stable |
| **11** | Connect wiring | Ports match software configuration |
| **12** | Secure cables | No interference with moving systems |
| **13** | Mechanical verification | Robot rolls and steers freely |
| **14** | Sensor verification | Sensors produce valid readings |
| **15** | Open calibration | Navigation and parking tested |
| **16** | Obstacle calibration | Detection, avoidance and recovery tested |

</div>

<p align="center">
  <strong>
    Build → Check → Add Next System → Check Again
  </strong>
</p>

---

# 5.2.6 Step 1 — Construct the Lower Chassis

The lower chassis is the reference structure for every other subsystem.

<p align="center">
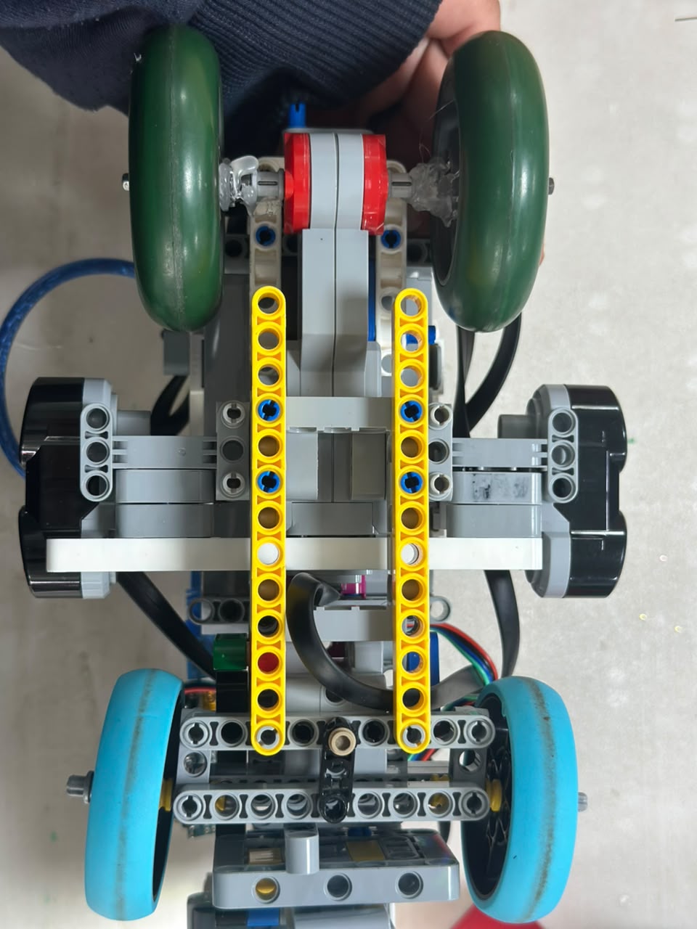
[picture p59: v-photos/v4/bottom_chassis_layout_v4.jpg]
Cheese v4 lower chassis
  
</p>

The current v4 chassis is intentionally simpler than the previous design.

The team removed unnecessary structural elements rather than adding reinforcement everywhere.

### Construction objectives

- maintain a rigid central structure,
- provide secure motor supports,
- maintain left/right alignment,
- leave space for the steering linkage,
- support the EV3 at a lower position,
- and avoid unnecessary mass.

### Before continuing

Check that:

- beams are not visibly twisted,
- pins are fully inserted,
- axles are not under sideways load,
- steering space remains clear,
- and the chassis sits naturally on a flat surface.

---

# 5.2.7 Step 2 — Rear Drive Assembly

The rear wheels provide propulsion.

<p align="center">
  Cheese v4 rear drive wheels
</p>

The rear axle should be installed so that both wheels rotate without rubbing nearby LEGO elements.

The assembly must remain mechanically aligned because unnecessary resistance changes how the robot responds to the same motor command.

### Manual check

Rotate the rear wheels before powering the robot.

They should rotate without:

- strong friction,
- axle binding,
- structural rubbing,
- or excessive side movement.

---

# 5.2.8 Step 3 — Large Drive Motor

Cheese uses an EV3 Large Motor as its propulsion actuator.

<p align="center">
  Large Motor mounting
</p>

<p align="center">
  Large Motor side view
</p>

The current v4 Large Motor is installed horizontally.

### Electrical connection

<p align="center">
  <strong>Large Motor → EV3 Output B</strong>
</p>

### Mechanical chain

<p align="center">
  <strong>Large Motor → Drive Transmission → Rear Axle → Rear Wheels</strong>
</p>

After mounting it, verify that the motor itself cannot shift inside the chassis.

---

# 5.2.9 Step 4 — Ackermann Steering Assembly

The front steering system is one of the most mechanically sensitive assemblies on Cheese.

<p align="center">
  Cheese v4 Ackermann steering
</p>

The system uses a mechanical linkage so that the front wheels can follow different paths during a turn.

This is important because the wheel on the inside of a corner follows a smaller radius than the outside wheel.

### Assembly check

Move the mechanism manually through:

<p align="center">
  <strong>
    Full Left → Center → Full Right → Center
  </strong>
</p>

There should be:

- no binding,
- no beam contact,
- no cable contact,
- no wheel/chassis collision,
- and no excessive looseness.

<p align="center">
  <a href="../../schemes/steering_comparison_v3_to_v4.pdf">
    <strong>Open the Cheese v3 → v4 Steering Comparison</strong>
  </a>
</p>

---

# 5.2.10 Step 5 — Steering Motor

The EV3 Medium Motor controls the steering mechanism.

<p align="center">
  Cheese Medium steering motor
</p>

### Electrical connection

<p align="center">
  <strong>Medium Motor → EV3 Output A</strong>
</p>

The motor should be mechanically secure because movement of the motor mount changes the effective steering angle.

### Establish physical center

Before autonomous testing:

1. place the steering approximately at its mechanical center,
2. verify both front wheels point approximately forward,
3. check available travel to the left,
4. check available travel to the right,
5. then establish the software steering reference.

A badly misaligned mechanical center should not be hidden with a large software correction.

---

# 5.2.11 Step 6 — Front Wheel Assemblies

The current front wheels are the distinctive light-blue wheel assemblies shown on the real robot.

<p align="center">
  Cheese v4 front wheel assemblies
</p>

Only the **front wheel assemblies** were changed during the v4 redesign.

The rear drive wheels remain a different EV3/Technic-style wheel assembly.

This distinction is important when reproducing Cheese:

<p align="center">
  <strong>
    Front Wheels ≠ Rear Wheels
  </strong>
</p>

After installation, verify:

- both wheels rotate freely,
- both steering pivots move freely,
- the wheels clear the chassis,
- and both wheels maintain appropriate floor contact.

---

# 5.2.12 Step 7 — EV3 Brick Placement

The EV3 Brick is mounted relatively low and flat in Cheese v4.

<p align="center">
  Cheese v4 low EV3 position
</p>

<p align="center">
  Cheese EV3 top view
</p>

The screen remains accessible from above.

This arrangement also keeps:

- input ports accessible,
- output ports accessible,
- USB accessible,
- and the battery reachable.

---

# 5.2.13 Step 8 — Battery Access

The EV3 rechargeable battery should remain accessible after assembly.

<p align="center">
  EV3 battery access
</p>

This is a practical design requirement.

Competition testing involves repeated charging, inspection and restarting, so routine battery access should not require rebuilding major structural sections.

Battery condition should also be checked before interpreting a change in robot behavior as a software problem.

---

# 5.2.14 Step 9 — Ultrasonic Sensor Installation

Cheese v4 uses **three EV3 Ultrasonic Sensors**.

<div align="center">

| Sensor | Port | Primary Role |
| :--- | :---: | :--- |
| **Left Ultrasonic** | **Input 1** | Left-wall distance |
| **Right Ultrasonic** | **Input 2** | Right-wall distance |
| **Front Ultrasonic** | **Input 3** | Front safety / recovery |

</div>

### Left sensor

<p align="center">
  Left ultrasonic placement
</p>

### Right sensor

<p align="center">
  Right ultrasonic placement
</p>

### Front sensor

<p align="center">
  Front ultrasonic placement
</p>

### Side relationship

<p align="center">
  Side ultrasonic layout
</p>

Sensor orientation matters as much as the sensor itself.

A sensor that is several degrees out of alignment can produce a different wall measurement even when the code is unchanged.

---

# 5.2.15 Step 10 — Color Sensor Installation

The EV3 Color Sensor is mounted underneath the robot facing the field.

<p align="center">
  Cheese Color Sensor placement
</p>

### Connection

<p align="center">
  <strong>Color Sensor → EV3 Input 4</strong>
</p>

The sensor should be positioned close to the field without physically touching it.

<p align="center">
  Cheese Color Sensor floor clearance
</p>

The floor gap is especially important.

Too high can reduce reading consistency.

Too low can cause the sensor or its support to drag during motion.

An earlier light-blocking cover was removed after it created physical interference. The current v4 arrangement instead uses the improved sensor position and floor clearance.

---

# 5.2.16 Step 11 — HuskyLens Installation

The HuskyLens provides the vision input used during the Obstacle Challenge.

<p align="center">
  HuskyLens placement
</p>

Its angle should remain stable.

<p align="center">
  HuskyLens side angle
</p>

The camera must have an unobstructed forward field of view.

A change in camera angle can alter:

- when a pillar enters the image,
- its apparent horizontal position,
- detection consistency,
- and therefore avoidance timing.

### Current trained mapping

<div align="center">

| Obstacle | HuskyLens ID | Required Passing Side |
| :---: | :---: | :---: |
| **Green Pillar** | **ID 1** | **Left** |
| **Red Pillar** | **ID 2** | **Right** |

</div>

---

# 5.2.17 Step 12 — Arduino Nano

The Arduino Nano provides the communication bridge between the HuskyLens and EV3.

<p align="center">
  Arduino Nano position
</p>

The current Nano does not require a heavy dedicated tower.

Instead, its placement prioritizes:

- low added mass,
- safe wiring,
- USB access,
- and separation from moving mechanisms.

---

# 5.2.18 HuskyLens → Nano Wiring

<p align="center">
  HuskyLens Arduino Nano wiring
</p>

The current I²C connection is:

<div align="center">

| HuskyLens | Arduino Nano |
| :---: | :---: |
| **VCC / +** | **5V** |
| **GND / −** | **GND** |
| **SDA / T** | **A4** |
| **SCL / R** | **A5** |

</div>

<p align="center">
  <strong>HuskyLens → I²C → Arduino Nano</strong>
</p>

For the detailed wiring reference:

<p align="center">
  <a href="../../schemes/arduino_nano_huskylens_wiring_v4.pdf">
    <strong>Open Arduino Nano ↔ HuskyLens Wiring Diagram</strong>
  </a>
</p>

---

# 5.2.19 Nano → EV3 Communication

The Nano communicates with the EV3 through USB.

<p align="center">
  EV3 USB to Arduino Nano
</p>

The complete vision data path is therefore:

<p align="center">
  <strong>
    Colored Pillar → HuskyLens → I²C → Arduino Nano → USB Serial → EV3
  </strong>
</p>

The shorter USB cable used in v4 reduces unnecessary cable length around the robot.

---

# 5.2.20 Complete Port Map

<div align="center">

| Device | Connection |
| :--- | :---: |
| **Medium Steering Motor** | **Output A** |
| **Large Drive Motor** | **Output B** |
| **Left Ultrasonic Sensor** | **Input 1** |
| **Right Ultrasonic Sensor** | **Input 2** |
| **Front Ultrasonic Sensor** | **Input 3** |
| **Color Sensor** | **Input 4** |
| **Arduino Nano** | **EV3 USB** |
| **HuskyLens** | **Nano I²C** |

</div>

### EV3 inputs

<p align="center">
  EV3 sensor input ports
</p>

### EV3 outputs

<p align="center">
  EV3 motor output ports
</p>

The physical connections must match the software configuration.

---

# 5.2.21 Cable Routing

Once all devices are connected, route the cables around the mechanical systems.

<p align="center">
  Cheese v4 wiring overview
</p>

Cheese does not require perfectly hidden wiring.

It requires **safe wiring**.

The important requirement is that cables do not interfere with:

- steering linkage,
- front wheel movement,
- rear wheels,
- drive axle,
- or sensor view.

<p align="center">
  <strong>
    Electrical Cable in Moving Mechanism = Mechanical Failure Risk
  </strong>
</p>

---

# 5.2.22 Mechanical Verification

Before autonomous testing, Cheese should pass a complete physical inspection.

<div align="center">

| Check | Expected Result |
| :--- | :--- |
| Roll Cheese manually | Smooth movement |
| Rotate rear wheels | No abnormal binding |
| Move steering left/right | Free linkage movement |
| Return steering to center | Wheels return near neutral |
| Inspect motor mounts | No movement |
| Inspect EV3 | Secure |
| Inspect side Ultrasonics | Stable orientation |
| Inspect front Ultrasonic | Clear forward view |
| Inspect Color Sensor | Does not contact floor |
| Inspect HuskyLens | Stable forward angle |
| Inspect cables | No mechanical interference |

</div>

If one of these tests fails, fix the physical system before modifying software.

---

# 5.2.23 Sensor Verification

After mechanical inspection, test the sensors individually.

### Ultrasonics

Move a flat object toward each sensor.

The measured distance should decrease consistently.

### Color Sensor

Move the sensor across:

- neutral floor,
- blue marking,
- orange / recognized curve marking.

Verify that the software distinguishes the expected events.

### HuskyLens

Present real obstacle pillars individually.

Confirm:

<p align="center">
  <strong>Green → ID 1</strong><br>
  <strong>Red → ID 2</strong>
</p>

Do not begin avoidance tuning until recognition itself is sufficiently repeatable.

---

# 5.2.24 Software Verification Order

A full run should not be the first software test.

Use progressively larger tests.

<p align="center">
  <strong>
    Component → Subsystem → Combined Behavior → Full Challenge
  </strong>
</p>

For example:

<div align="center">

| Test Level | Example |
| :---: | :--- |
| **Component** | Read one ultrasonic |
| **Subsystem** | Wall-following correction |
| **Combined** | Wall following + corner |
| **Full system** | Complete three-lap Open run |

</div>

This makes failures much easier to isolate.

---

# 5.2.25 Open Challenge Build Validation

After assembly, the Open Challenge should be validated in this order:

<p align="center">
  <strong>
    Straight → PID → Walls → Corners → Curve Count → Recovery → 3 Laps → Parking
  </strong>
</p>

### Straight

Verify basic propulsion and steering center.

### PID

Verify that small distance errors produce small corrections instead of large oscillations.

### Wall protection

Test progressively closer wall positions.

### Corners

Check both entry and exit trajectory.

### Curve counting

Confirm that one physical curve corresponds to one valid count.

### Recovery

Test front safety behavior separately.

### Full run

Only then attempt three complete laps.

### Parking

Parking should be tested after curve counting is sufficiently reliable because the finish depends on progress tracking.

---

# 5.2.26 Open Challenge Verification Evidence

<p align="center">
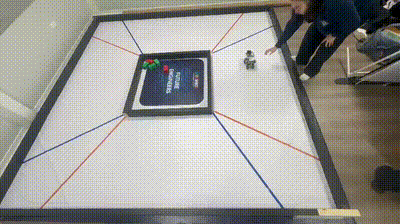
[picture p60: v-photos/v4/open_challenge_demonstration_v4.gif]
Cheese v4 Open Challenge demonstration
  
</p>

<p align="center">
  <em>
    Full Open Challenge testing demonstrates how the mechanical build,
    sensors and software operate together after assembly and calibration.
  </em>
</p>

A shorter corner demonstration can also be used to inspect steering behavior:

<p align="center">
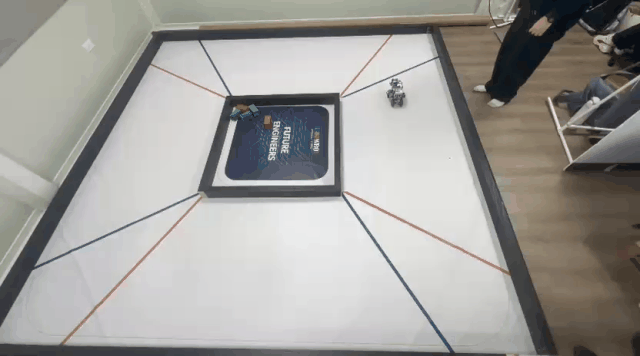
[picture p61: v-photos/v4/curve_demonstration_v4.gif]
Cheese v4 corner demonstration
  
</p>

---

# 5.2.27 Obstacle Challenge Build Validation

Obstacle calibration follows a different progression.

<p align="center">
  <strong>
    Detect → Identify → Choose Side → Avoid → Clear Pillar → Recover → Continue
  </strong>
</p>

Test one behavior at a time.

### 1. Detection

Can HuskyLens consistently see the pillar?

### 2. Identification

Is the correct ID returned?

### 3. Passing rule

- Green → left
- Red → right

### 4. Clearance

Does Cheese completely clear the obstacle?

### 5. Recovery

Does the robot return toward a useful trajectory after avoidance?

This final step is especially important because recovery after an obstacle remains one of the principal tuning challenges of the current system.

---

# 5.2.28 Obstacle Corner Verification

<p align="center">
  Cheese obstacle corner handling
</p>

<p align="center">
  <em>
    Real testing evidence showing the interaction between corner handling,
    sensing and obstacle navigation.
  </em>
</p>

Testing complete situations like this is performed only after the individual systems have already been checked.

---

# 5.2.29 Failure Isolation Guide

When something goes wrong, first identify **which system failed**.

<div align="center">

| Observed Failure | Inspect First |
| :--- | :--- |
| Strong drift while driving | Wheel alignment / drivetrain |
| Steering remains turned | Steering linkage / Medium Motor |
| Constant zig-zag | Sensor readings / PID response |
| Incorrect wall correction | Ultrasonic position / port |
| Front recovery missing | Front Ultrasonic |
| Incorrect curve count | Color Sensor / validation logic |
| HuskyLens sees pillar but EV3 does not react | Nano / USB communication |
| Correct recognition but pillar is hit | Avoidance timing / strength |
| Pillar cleared but robot later hits wall | Post-obstacle recovery |
| Parking starts early or late | Curve count |
| Same code suddenly behaves weaker | Battery / mechanical resistance |

</div>

<p align="center">
  <strong>
    Failure → Isolate → Change One Variable → Retest
  </strong>
</p>

---

# 5.2.30 Construction Mistakes to Avoid

### Do not use software to compensate for severe mechanical problems

A crooked wheel is not a PID problem.

### Do not change sensor position casually

Sensor geometry is part of the calibration.

### Do not allow the Color Sensor to drag

The robot changes height slightly during motion and curves.

### Do not leave the HuskyLens loose

Camera movement changes obstacle geometry.

### Do not route cables through steering

The cable can physically restrict the mechanism.

### Do not rebuild removed v3 systems

Cheese v4 does **not** use the previous auxiliary-light system or its large supporting structure.

### Do not assume front and rear wheels are interchangeable

They are intentionally different assemblies.

---

# 5.2.31 Final Pre-Run Checklist

### Mechanical

- [ ] Chassis rigid
- [ ] No loose structural pieces
- [ ] Rear wheels rotate freely
- [ ] Front wheels rotate freely
- [ ] Steering moves through full required range
- [ ] Steering returns to center
- [ ] Large Motor secure
- [ ] Medium Motor secure

### Controller and Power

- [ ] EV3 secure
- [ ] Battery charged
- [ ] Battery accessible
- [ ] EV3 boots normally

### Ports

- [ ] Output A → Medium Motor
- [ ] Output B → Large Motor
- [ ] Input 1 → Left Ultrasonic
- [ ] Input 2 → Right Ultrasonic
- [ ] Input 3 → Front Ultrasonic
- [ ] Input 4 → Color Sensor
- [ ] USB → Arduino Nano

### Sensors

- [ ] Left Ultrasonic stable
- [ ] Right Ultrasonic stable
- [ ] Front Ultrasonic stable
- [ ] Color Sensor has correct floor clearance
- [ ] Color readings verified

### Vision

- [ ] HuskyLens powered
- [ ] Camera angle stable
- [ ] Green = ID 1
- [ ] Red = ID 2
- [ ] Nano communication verified

### Wiring

- [ ] No cable contacts steering
- [ ] No cable contacts wheels
- [ ] USB cable secure
- [ ] HuskyLens wires secure

---

# 5.2.32 Reproducibility Test

A reconstruction is not complete simply because it visually resembles Cheese.

It should pass four verification levels.

<div align="center">

| Level | Requirement |
| :---: | :--- |
| **1 — Mechanical** | Robot rolls and steers correctly |
| **2 — Electrical** | Motors and sensors are correctly connected |
| **3 — Sensing** | Distance, floor and vision data are valid |
| **4 — Autonomous** | Systems work together during navigation |

</div>

<p align="center">
  <strong>
    Similar Appearance ≠ Functional Reproduction
  </strong>
</p>

A reproducible Cheese must preserve the relationships between its systems.

---

# 5.2.33 Construction Reference Hierarchy

When reproducing the robot, use the repository references in this order:

<div align="center">

| Priority | Reference | Best Used For |
| :---: | :--- | :--- |
| **1** | **Real v4 photographs** | Exact physical arrangement |
| **2** | **Build Assembly Guide** | Understanding system relationships |
| **3** | **Wiring diagrams** | Electrical architecture |
| **4** | **Bill of Materials** | Component inventory |
| **5** | **Software documentation** | Port and behavior verification |

</div>

The real photographs have the highest priority whenever a simplified diagram does not show a small connection clearly.

---

# 5.2.34 Related Construction Resources

<div align="center">

| Resource | Purpose |
| :--- | :--- |
| [`5.1 Bill of Materials`](5.1-bill-of-materials.md) | Components required to reproduce Cheese |
| [`1.2 Structural Components`](../01-mobility-and-mechanical-design/1.2-structural-component.mds.md) | LEGO structural architecture |
| [`1.3 Steering and Drive`](../01-mobility-and-mechanical-design/1.3-steering-and-drive.md) | Steering and drivetrain |
| [`1.4 Chassis Explanation`](../01-mobility-and-mechanical-design/1.4-chassis-explanation.md) | Chassis design reasoning |
| [`2.1 Power Supply and EV3`](../02-power-and-sensor-architecture/2.1-power-supply-and-ev3.md) | Power architecture |
| [`2.2 Wiring Diagram`](../02-power-and-sensor-architecture/2.2-wiring-diagram.md) | Electrical connections |
| [`2.3 Sensor Selection and Placement`](../02-power-and-sensor-architecture/2.3-sensor-selection-and-placement.md) | Sensor geometry |
| [`2.4 Sensor Calibration`](../02-power-and-sensor-architecture/2.4-sensor-calibration.md) | Calibration |
| [`3.3 Open Challenge`](../03-software-and-obstacle-strategy/3.3-open-challenge.md) | Open navigation |
| [`3.4 Obstacle Challenge`](../03-software-and-obstacle-strategy/3.4-obstacle-challenge.md) | Obstacle navigation |
| [`4.1 Design Decision Log`](../04-engineering-decisions/4.1-design-decision-log.md) | Why v4 was built this way |
| [`4.2 What Didn't Work`](../04-engineering-decisions/4.2-what-didnt-work.md) | Failures that shaped v4 |

</div>

### Technical schemes

<p align="center">
  <a href="../../schemes/Cheese_V4_Build_Assembly_Guide.png">
    <strong>Cheese v4 Build & Assembly Guide</strong>
  </a>
  &nbsp;&nbsp;•&nbsp;&nbsp;
  <a href="../../schemes/Cheese_V4_Complete_System_Architecture_Wiring_Diagram.pdf">
    <strong>Complete System Architecture</strong>
  </a>
  &nbsp;&nbsp;•&nbsp;&nbsp;
  <a href="../../schemes/arduino_nano_huskylens_wiring_v4.pdf">
    <strong>HuskyLens ↔ Nano Wiring</strong>
  </a>
</p>

---

# 5.2.35 Final Build Philosophy

Cheese v4 is not defined by one component.

Its behavior comes from the relationship between:

<p align="center">
  <strong>
    Chassis + Steering + Drive + Sensors + Vision + Wiring + Software
  </strong>
</p>

A mechanical change can alter a sensor reading.

A sensor change can alter a steering correction.

A steering change can alter a corner exit.

A corner exit can alter when the next obstacle enters the camera.

For that reason, reproducing Cheese means reproducing **the system**, not simply its appearance.

<p align="center">
  <strong>
    Correct Components<br>
    + Correct Geometry<br>
    + Correct Connections<br>
    + Correct Calibration<br>
    = Reproducible Cheese v4
  </strong>
</p>

<p align="center">
  ✦ ─── ⋆⋅☆⋅⋆ ─── (❁´◡`❁) ─── ⋆⋅☆⋅⋆ ─── ✦
</p>

<p align="center">
  <a href="https://github.com/Quesovamos2662/WRO2026_FE_Go-Cheese#general-project-index">
    
  </a>
</p>

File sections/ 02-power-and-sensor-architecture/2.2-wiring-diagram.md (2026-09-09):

<h1 align="center">ᯓ★ 2.2 Wiring Diagram ᯓ★</h1>

<p align="center">
  
  
  
  
</p>

<p align="center">
  <em>
    This section documents how the electronic components of Cheese v4 are
    physically and logically interconnected.
  </em>
</p>

<p align="center">
  ✦ ─── ⋆⋅☆⋅⋆ ─── (❁´◡`❁) ─── ⋆⋅☆⋅⋆ ─── ✦
</p>

Cheese v4 combines the LEGO EV3 control system with an external vision subsystem.

The wiring architecture must connect four different types of devices:

- **controller** — EV3 Brick,
- **actuators** — Large and Medium motors,
- **LEGO sensors** — ultrasonic and color sensors,
- **external vision electronics** — Arduino Nano and HuskyLens.

The complete signal chain can be summarized as:

<p align="center">
  <strong>
    Sensors → EV3 → Navigation Logic → Motors
  </strong>
</p>

while the external vision chain follows:

<p align="center">
  <strong>
    HuskyLens → Arduino Nano → EV3 → Navigation Logic
  </strong>
</p>

---

## ❀ 2.2.1 Complete System Architecture ────୨ৎ────────୨ৎ────

The highest-level diagram documents the relationship between every major electronic subsystem in Cheese v4.

It includes:

- EV3 rechargeable battery,
- EV3 Brick,
- EV3 Large Motor,
- EV3 Medium Motor,
- three ultrasonic sensors,
- EV3 Color Sensor,
- Arduino Nano,
- HuskyLens,
- USB communication,
- and I2C communication.

<p align="center">
  <a href="../../schemes/Cheese_V4_Complete_System_Architecture_Wiring_Diagram.pdf">
    
  </a>
</p>

<p align="center">
  <em>
    Complete system-level architecture of Cheese v4, showing power,
    sensing, control, actuation, and vision communication.
  </em>
</p>

This diagram answers the broadest question:

> **How are all of Cheese's electronic systems related?**

---

## ❀ 2.2.2 Technical Wiring Diagram ────୨ৎ────────୨ৎ────

The complete architecture is useful for understanding the system, but a more technical representation is needed for engineering documentation.

<p align="center">
  <a href="../../schemes/cheese_v4_technical_wiring_diagram.pdf">
    
  </a>
</p>

<p align="center">
  <em>
    Engineering-style schematic of the current Cheese v4 electrical architecture.
  </em>
</p>

The technical diagram focuses on the actual electrical relationships rather than the physical appearance of the robot.

The two diagrams therefore serve different purposes:

| Diagram | Main Question |
| :--- | :--- |
| **Complete System Architecture** | How do all subsystems interact? |
| **Technical Wiring Diagram** | How are the electrical connections organized? |

---

## ❀ 2.2.3 EV3 Brick Wiring ────୨ৎ────────୨ৎ────

The EV3 Brick is the central connection point of Cheese.

For clarity, its connections are also documented independently.

<p align="center">
  <a href="../../schemes/ev3_brick_wiring_v4.pdf">
    
  </a>
</p>

<p align="center">
  <em>
    Dedicated EV3 wiring diagram showing the controller-side connections
    separately from the complete system.
  </em>
</p>

The EV3 separates the robot into two primary connection groups:

| Connection Group | Purpose |
| :--- | :--- |
| **Sensor inputs** | Bring environmental measurements into the EV3 |
| **Motor outputs** | Send commands from the EV3 to the actuators |

This creates a simple control direction:

```text
Environment
    ↓
 Sensors
    ↓
EV3 Inputs
    ↓
Navigation Software
    ↓
EV3 Outputs
    ↓
 Motors
    ↓
Robot Movement
```

---

## ❀ 2.2.4 Physical EV3 Port Evidence ────୨ৎ────────୨ৎ────

The wiring diagrams show the intended architecture.

The photographs below show the **real implementation on Cheese v4**.

<p align="center">
  EV3 input ports connected on Cheese v4
  &nbsp;
  EV3 output ports connected on Cheese v4
</p>

<p align="center">
  <em>
    Physical evidence of the sensor-input and motor-output connections
    used on the current robot.
  </em>
</p>

This distinction is important for reproducibility:

> **The schematic explains the design. The photographs prove the implementation.**

---

## ❀ 2.2.5 Motor Connections ────୨ৎ────────୨ৎ────

Cheese uses separate motors for propulsion and steering.

| Actuator | Type | Function |
| :--- | :--- | :--- |
| **Drive Motor** | EV3 Large Motor | Provides propulsion |
| **Steering Motor** | EV3 Medium Motor | Controls the front steering linkage |

Separating these functions allows the navigation software to control:

- forward/reverse movement,
- driving speed,
- steering angle,
- wall corrections,
- curve behavior,
- obstacle avoidance,
- and parking corrections.

The EV3 therefore converts navigation decisions into two independent physical outputs:

```text
                    ┌──→ Large Motor → Propulsion
Navigation Logic ───┤
                    └──→ Medium Motor → Steering
```

---

## ❀ 2.2.6 LEGO Sensor Connections ────୨ৎ────────୨ৎ────

Cheese v4 uses four primary LEGO sensing devices:

| Sensor | Quantity | Main Information |
| :--- | :---: | :--- |
| **Ultrasonic Sensor** | 3 | Distance |
| **Color Sensor** | 1 | Floor color |

The three ultrasonic sensors observe different regions around Cheese:

```text
                 FRONT
                   ↑
             [ Front US ]

 [ Left US ]     CHEESE     [ Right US ]

                   ↓
              Color Sensor
               toward floor
```

Their physical selection, mounting positions, and engineering purpose are documented in:

> **Section 2.3 — Sensor Selection & Placement**

Their calibration is documented in:

> **Section 2.4 — Sensor Calibration**

This prevents the wiring section from repeating the sensor-design discussion.

---

## ❀ 2.2.7 External Vision Interface ────୨ৎ────────୨ৎ────

The HuskyLens introduces a non-LEGO vision subsystem into Cheese.

Instead of treating the camera as a normal EV3 sensor, the system uses an **Arduino Nano as a communication bridge**.

The architecture is:

```text
HuskyLens
    │
    │ I2C
    ▼
Arduino Nano
    │
    │ USB
    ▼
EV3 Brick
    │
    ▼
Navigation Software
```

The devices have different responsibilities:

| Device | Responsibility |
| :--- | :--- |
| **HuskyLens** | Performs visual obstacle recognition |
| **Arduino Nano** | Receives and transfers vision information |
| **EV3 Brick** | Interprets the data and decides robot movement |

This separation keeps the camera-recognition subsystem modular.

---

## ❀ 2.2.8 Arduino Nano ↔ HuskyLens Wiring ────୨ৎ────────୨ৎ────

The HuskyLens communicates with the Arduino Nano through **I2C**.

The documented connection is:

| HuskyLens | Arduino Nano | Function |
| :--- | :--- | :--- |
| **VCC** | **5V** | Power |
| **GND** | **GND** | Common ground |
| **SDA** | **A4 / SDA** | I2C data |
| **SCL** | **A5 / SCL** | I2C clock |

A dedicated diagram documents this interface:

<p align="center">
  <a href="../../schemes/arduino_nano_huskylens_wiring_v4.pdf">
    
  </a>
</p>

<p align="center">
  <em>
    Pin-level reference for the power and I2C connections between the
    Arduino Nano and HuskyLens.
  </em>
</p>

The signal path is:

<p align="center">
  <strong>
    HuskyLens → I2C → Arduino Nano
  </strong>
</p>

---

## ❀ 2.2.9 EV3 ↔ Arduino Nano USB Connection ────୨ৎ────────୨ৎ────

After receiving information from the HuskyLens, the Arduino Nano transfers vision information to the EV3 through USB communication.

<p align="center">
  USB connection between EV3 Brick and Arduino Nano
</p>

<p align="center">
  <em>
    Physical USB communication connection between the EV3 Brick and
    Arduino Nano in Cheese v4.
  </em>
</p>

The complete vision communication path is therefore:

<p align="center">
  <strong>
    HuskyLens → I2C → Nano → USB → EV3
  </strong>
</p>

This is different from the normal LEGO sensors, which communicate directly with the EV3 through its sensor ports.

---

## ❀ 2.2.10 Physical Arduino Nano Wiring ────୨ৎ────────୨ৎ────

The Nano/HuskyLens diagram documents the electrical connections, while the physical robot provides evidence of the actual implementation.

<p align="center">
  Arduino Nano wiring close-up on Cheese v4
  &nbsp;
  Arduino Nano position on Cheese v4
</p>

<p align="center">
  <em>
    Physical implementation of the Arduino Nano communication interface.
  </em>
</p>

The Nano is an electronic interface rather than a structural component.

Its position therefore prioritizes:

- cable access,
- secure electrical connections,
- short communication routing,
- and avoiding interference with moving mechanisms.

---

## ❀ 2.2.11 Physical Wiring Overview ────୨ৎ────────୨ৎ────

The complete physical implementation can be seen below.

<p align="center">
  Complete physical wiring overview of Cheese v4
</p>

<p align="center">
  <em>
    Physical wiring implementation of the current Cheese v4 architecture.
  </em>
</p>

Cable routing must coexist with:

- the moving steering linkage,
- front wheels,
- EV3 Brick,
- motors,
- ultrasonic sensors,
- floor sensor,
- camera,
- and Arduino Nano.

Therefore, wiring is also a mechanical consideration.

A correct electrical connection is not enough if the cable interferes with a moving component.

---

## ❀ 2.2.12 Four Levels of Wiring Documentation ────୨ৎ────────୨ৎ────

Instead of relying on one diagram, Cheese v4 documents the electrical system at four levels.

### Level 1 — Complete System

<p align="center">
  <a href="../../schemes/Cheese_V4_Complete_System_Architecture_Wiring_Diagram.pdf">
    
  </a>
</p>

Shows how the major systems relate.

### Level 2 — Technical Schematic

<p align="center">
  <a href="../../schemes/cheese_v4_technical_wiring_diagram.pdf">
    
  </a>
</p>

Shows the architecture as an engineering wiring diagram.

### Level 3 — Component Interfaces

<p align="center">
  <a href="../../schemes/ev3_brick_wiring_v4.pdf">
    
  </a>
  &nbsp;
  <a href="../../schemes/arduino_nano_huskylens_wiring_v4.pdf">
    
  </a>
</p>

Shows the two interfaces that require additional detail.

### Level 4 — Physical Implementation

<p align="center">
  Physical wiring implementation
</p>

Shows that the documented architecture exists on the actual robot.

Together:

<p align="center">
  <strong>
    Architecture → Technical Wiring → Interfaces → Physical Robot
  </strong>
</p>

---

## ❀ 2.2.13 Wiring Evidence Map ────୨ৎ────────୨ৎ────

| Evidence | Repository File | What It Documents |
| :--- | :--- | :--- |
| **Complete architecture** | [`Cheese_V4_Complete_System_Architecture_Wiring_Diagram.pdf`](../../schemes/Cheese_V4_Complete_System_Architecture_Wiring_Diagram.pdf) | Complete electronic architecture |
| **Technical wiring** | [`cheese_v4_technical_wiring_diagram.pdf`](../../schemes/cheese_v4_technical_wiring_diagram.pdf) | Engineering schematic |
| **EV3 Brick wiring** | [`ev3_brick_wiring_v4.pdf`](../../schemes/ev3_brick_wiring_v4.pdf) | Controller-side wiring |
| **Nano ↔ HuskyLens wiring** | [`arduino_nano_huskylens_wiring_v4.pdf`](../../schemes/arduino_nano_huskylens_wiring_v4.pdf) | Vision-interface wiring |
| **EV3 input ports** | [`ev3_input_ports_v4.jpg`](../../v-photos/v4/ev3_input_ports_v4.jpg) | Physical sensor connections |
| **EV3 output ports** | [`ev3_output_ports_v4.jpg`](../../v-photos/v4/ev3_output_ports_v4.jpg) | Physical actuator connections |
| **EV3 → Nano USB** | [`ev3_usb_to_nano_v4.jpg`](../../v-photos/v4/ev3_usb_to_nano_v4.jpg) | External communication connection |
| **Nano wiring close-up** | [`arduino_nano_wiring_closeup_v4.jpg`](../../v-photos/v4/arduino_nano_wiring_closeup_v4.jpg) | Physical Nano wiring |
| **Nano position** | [`arduino_nano_position_v4.jpg`](../../v-photos/v4/arduino_nano_position_v4.jpg) | Nano integration |
| **Complete physical wiring** | [`wiring_overview_v4.jpg`](../../v-photos/v4/wiring_overview_v4.jpg) | Overall real implementation |

---

## ✦ Engineering Decisions & Lessons ─── ⋆⋅☆⋅⋆ ───

### 1. One diagram was not enough

A system-level diagram is useful for understanding Cheese, but it cannot show every connection clearly.

Separating the documentation into multiple levels makes the architecture easier to reproduce.

### 2. LEGO and external electronics require a defined interface

The LEGO sensors connect directly to the EV3.

The HuskyLens does not follow the same path.

Its information follows:

> **HuskyLens → Nano → EV3**

Documenting this difference prevents confusion when reproducing the robot.

### 3. Electrical diagrams and physical photographs serve different purposes

A schematic explains **where a connection should go**.

A photograph shows **how the team actually implemented it**.

Both are useful engineering evidence.

### 4. Cable routing is part of mechanical design

Wires must not interfere with steering, wheels, sensors, or moving structural components.

Therefore, wiring decisions cannot be separated completely from mechanical design.

### 5. Modular documentation improves debugging

When a problem appears, the team can inspect the system by layer:

```text
Sensor
  ↓
Connection
  ↓
Interface
  ↓
EV3
  ↓
Software
  ↓
Motor
```

This makes it easier to determine whether a failure is caused by sensing, communication, control, or physical movement.

---

## ✦ 2.2 Final Wiring Summary ─── ⋆⋅☆⋅⋆ ───

Cheese v4 combines a standard LEGO EV3 control architecture with an external Arduino Nano and HuskyLens vision subsystem.

The EV3 remains the central controller.

The LEGO sensors and motors connect through the EV3 architecture, while obstacle-vision information follows a separate communication path:

<p align="center">
  <strong>
    HuskyLens → I2C → Arduino Nano → USB → EV3
  </strong>
</p>

The electrical architecture is documented using:

1. a **Complete System Architecture**,
2. a **Technical Wiring Diagram**,
3. an **EV3 Brick Wiring Diagram**,
4. a **Nano ↔ HuskyLens Wiring Diagram**,
5. and photographs of the physical implementation.

Together, these provide both the conceptual and physical information needed to understand and reproduce the current Cheese v4 wiring architecture.

<p align="center">
  ✦ ─── ⋆⋅☆⋅⋆ ─── (❁´◡`❁) ─── ⋆⋅☆⋅⋆ ─── ✦
</p>

<p align="center">
  <a href="https://github.com/Quesovamos2662/WRO2026_FE_Go-Cheese#general-project-index">
    
  </a>
</p>

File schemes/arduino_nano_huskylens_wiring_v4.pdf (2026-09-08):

# Wiring Diagram Arduino Nano to HuskyLens

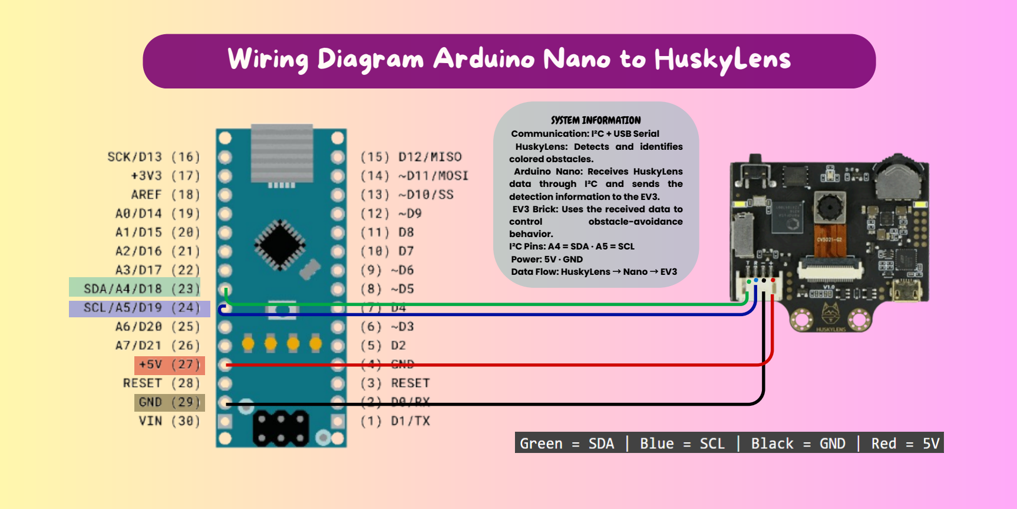
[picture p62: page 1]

SYSTEM INFORMATION
Communication: I²C + USB Serial HuskyLens: Detects and identifies colored obstacles.
Arduino Nano: Receives HuskyLens data through I²C and sends the detection information to the EV3.
EV3 Brick: Uses the received data to
control | obstacle-avoidance
behavior.
I²C Pins: A4 = SDA · A5 = SCL
Power: 5V · GND
Data Flow: HuskyLens → Nano → EV3

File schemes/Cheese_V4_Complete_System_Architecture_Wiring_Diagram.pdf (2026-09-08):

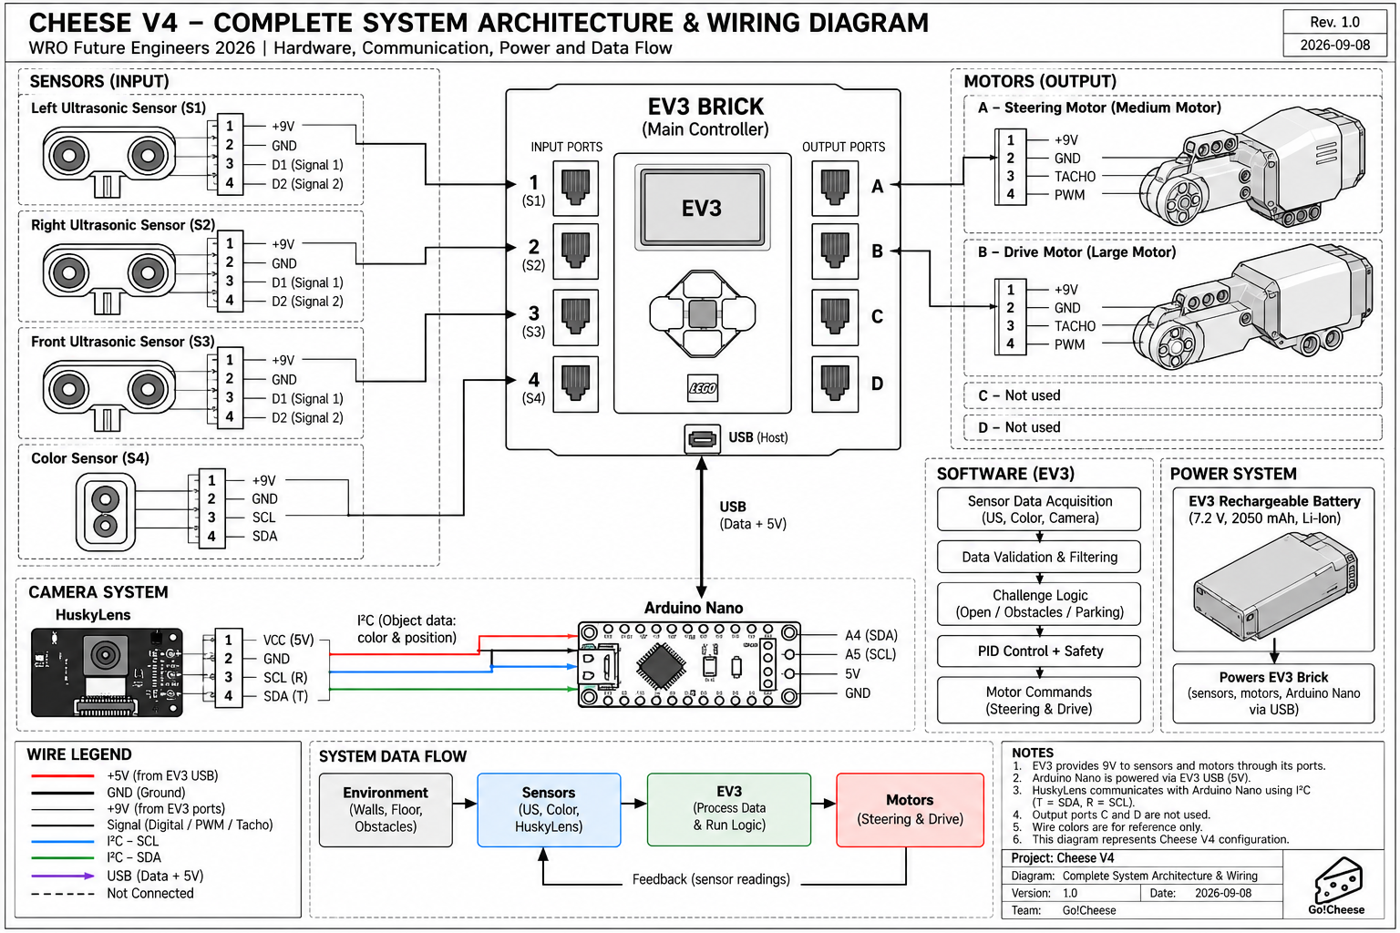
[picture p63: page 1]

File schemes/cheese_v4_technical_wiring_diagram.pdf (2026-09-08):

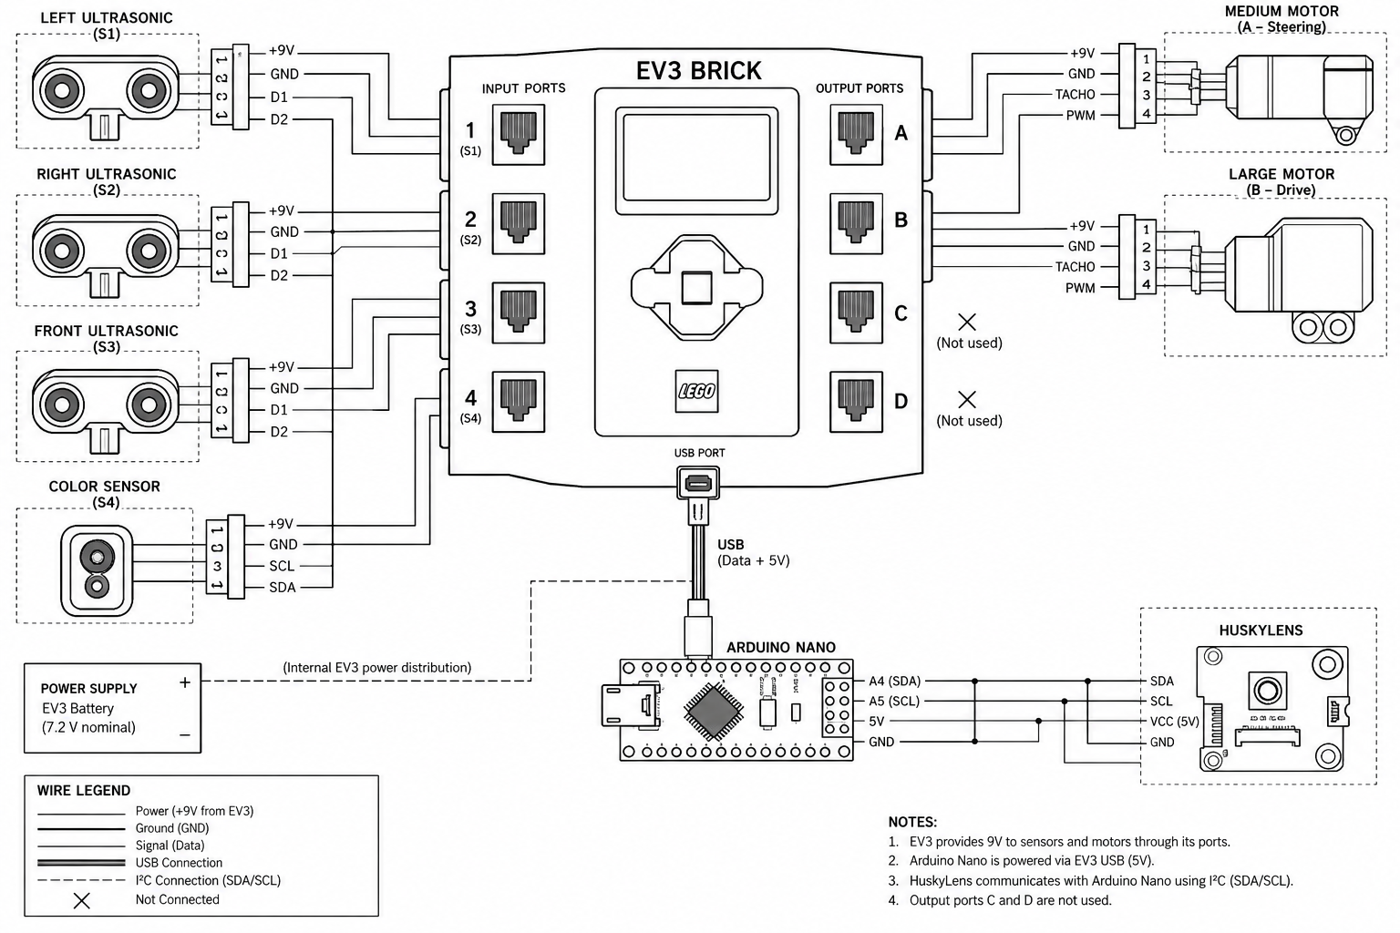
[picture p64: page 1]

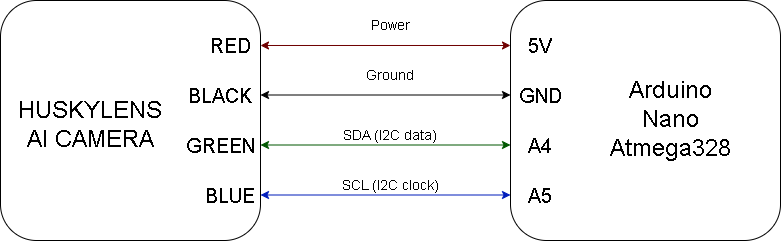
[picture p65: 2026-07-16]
img/HuskyLens_to_Arduino_Nano_Wiring.png

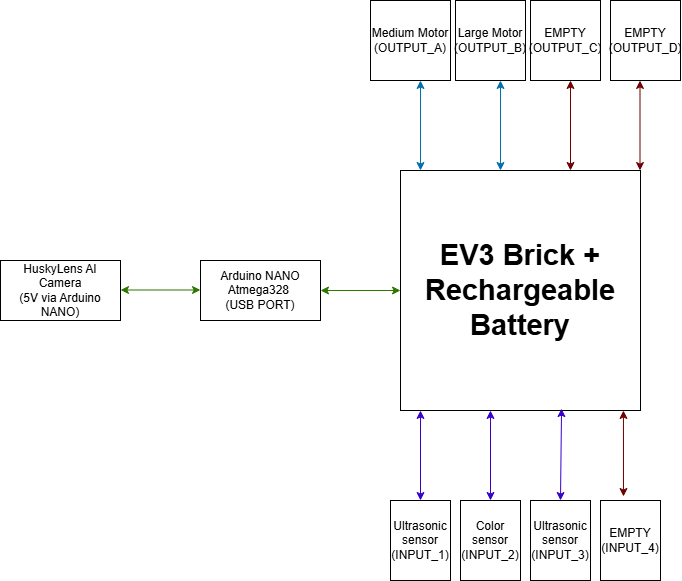
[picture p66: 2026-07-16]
img/Wiring Diagram Topology.png

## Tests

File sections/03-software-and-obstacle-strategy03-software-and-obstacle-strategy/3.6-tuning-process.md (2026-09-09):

<h1 align="center">ᯓ★ 3.6 Tuning Process ᯓ★</h1>

<p align="center">
  
  
  
  
</p>

<p align="center">
  <em>
    Cheese v4 was developed through repeated testing:
    observe a failure, identify its cause, change one part of the system,
    test again, and keep the change only when performance improved.
  </em>
</p>

<p align="center">
  ✦ ─── ⋆⋅☆⋅⋆ ─── 🧀🔧 ─── ⋆⋅☆⋅⋆ ─── ✦
</p>

---

# ❀ 3.6.1 Tuning Philosophy ────୨ৎ────────୨ৎ────

Tuning Cheese was not simply changing values until the robot worked.

The team followed an engineering cycle:

```text
TEST
 ↓
OBSERVE FAILURE
 ↓
IDENTIFY CAUSE
 ↓
CHANGE ONE MAIN VARIABLE
 ↓
TEST AGAIN
 ↓
COMPARE
 ↓
KEEP / MODIFY / REVERSE
```

The main priority was:

```text
CONSISTENCY
    ↓
RELIABILITY
    ↓
SPEED
```

A faster robot is only useful if it can still complete the round reliably.

---

# ❀ 3.6.2 Real Tuning Order ────୨ৎ────────୨ৎ────

The order of tuning was important because later systems depended on earlier ones.

<div align="center">

| Order | Stage | Main Goal |
| :---: | :--- | :--- |
| **1** | Mechanical | Make Cheese lighter and easier to control |
| **2** | Color Sensor | Improve blue/orange detection |
| **3** | PID | Achieve stable wall navigation |
| **4** | Corners | Improve turn shape and exits |
| **5** | Parking | Stop correctly after 12 curves |
| **6** | Obstacles | Improve detection, avoidance and recovery |

</div>

```text
MECHANICS
    ↓
SENSORS
    ↓
NAVIGATION
    ↓
CORNERS
    ↓
PARKING
    ↓
OBSTACLES
```

This prevented the team from trying to solve mechanical problems only through software.

---

# ❀ 3.6.3 Mechanical Tuning ────୨ৎ────────୨ৎ────

One of the biggest improvements happened before software tuning.

Cheese v4 was reduced to **666 g**, compared with approximately **888.8 g** in v3.

Important mechanical changes included:

- reducing unnecessary structure,
- lowering and repositioning the EV3 Brick,
- changing the front wheel assemblies,
- simplifying the upper structure,
- removing the previous auxiliary lighting system,
- and creating a cleaner sensor arrangement.

<div align="center">

| Change | Effect |
| :--- | :--- |
| **Lower mass** | Easier acceleration, turning and recovery |
| **Improved EV3 position** | Better weight distribution |
| **New front wheels** | Better steering behavior |
| **Reduced upper structure** | Less unnecessary mass and complexity |
| **Cleaner sensor layout** | Easier calibration and maintenance |

</div>

The mechanical redesign made later PID and corner tuning more predictable.

---

# ❀ 3.6.4 Color Sensor Tuning ────୨ৎ────────୨ৎ────

Color detection was one of the early reliability problems.

Sunlight and sensor height affected readings during testing. In v4, the sensor remained in the same general structural area but was positioned slightly lower.

<p align="center">
  Cheese v4 color sensor floor gap
</p>

This improved floor detection enough that external light-blocking structures are no longer part of normal v4 operation.

The final strategy combines:

```text
COLOR DETECTION
      +
BLUE ↔ ORANGE SEQUENCE
      +
STEERING CONFIRMATION
      +
COOLDOWN
      ↓
VALID CURVE
```

<p align="center">
  Cheese v4 curve counting logic
</p>

Color tuning became important not only for lap counting, but also for activating parking at the correct point.

---

# ❀ 3.6.5 PID and Wall Tuning ────୨ৎ────────୨ৎ────

PID became the base of Open navigation.

The goal was not to force Cheese into the exact center every second. Instead, the controller was tuned to make the minimum correction necessary while still protecting the robot from the walls.

<p align="center">
  Cheese v4 minimum correction PID
</p>

The tuning process moved from:

```text
TOO MUCH CORRECTION
      ↓
ZIG-ZAG
```

toward:

```text
SMALL ERROR
   ↓
SMALL CORRECTION

LARGE ERROR
   ↓
STRONGER CORRECTION
```

Progressive wall protection was added for situations where normal PID alone was not enough.

This became especially useful during close-wall situations and imperfect curve exits.

---

# ❀ 3.6.6 Corner Tuning ────୨ৎ────────୨ৎ────

Corner tuning focused on finding the balance between turns that were too wide and turns that were too aggressive.

```text
TOO WIDE
   ↓
OUTER WALL RISK

TOO SHARP
   ↓
INNER WALL RISK

CONTROLLED CURVE
   ↓
USEFUL EXIT POSITION
```

Testing showed that the exit was just as important as the turn itself.

For Open:

```text
BAD EXIT
   ↓
LARGE PID CORRECTION
   ↓
ZIG-ZAG / WALL RISK
```

For Obstacles:

```text
BAD EXIT
   ↓
BAD CAMERA HEADING
   ↓
PILLAR APPEARS LATE
   ↓
LATE AVOIDANCE
```

The complete corner-handling system is documented in **Section 3.5**.

---

# ❀ 3.6.7 Front-Wall Recovery Tuning ────୨ৎ────────୨ৎ────

The front ultrasonic provides an additional safety layer.

<p align="center">
  Cheese v4 front wall recovery
</p>

Instead of allowing Cheese to continue toward a dangerous front-wall condition:

```text
FRONT TOO CLOSE
      ↓
CONFIRM
      ↓
REVERSE
      ↓
CREATE SAFE SPACE
      ↓
RETURN TO NAVIGATION
```

The reverse behavior was tuned carefully because an overly aggressive recovery could prevent one collision but leave the robot badly positioned afterward.

---

# ❀ 3.6.8 Parking Tuning ────୨ৎ────────୨ৎ────

Parking could only be tuned properly after curve counting became reliable.

```text
12 CURVES COMPLETE
        ↓
PARKING ACTIVATES
        ↓
COMPARE FRONT DISTANCE
        ↓
SLOW APPROACH
        ↓
FINAL CREEP
        ↓
STOP
```

<p align="center">
  Cheese v4 parking logic
</p>

The current system uses the starting front-distance reference instead of depending only on elapsed time.

Current observations:

- Cheese stops inside the parking area.
- Overshooting is not a main current problem.
- Stopping too short is not a main current problem.
- The final position can sometimes be slightly angled.
- Incorrect curve counting can still affect parking timing.

Parking is therefore functional but still receives final adjustments.

---

# ❀ 3.6.9 Obstacle Tuning ────୨ৎ────────୨ৎ────

Obstacle tuning remains the most experimental part of Cheese v4.

The current vision architecture is:

```text
HUSKYLENS
    ↓
ARDUINO NANO
    ↓
EV3
    ↓
CAMERA BIAS
    ↓
STEERING RESPONSE
```

<p align="center">
  Cheese v4 obstacle detection and camera bias
</p>

The current trained pillar mapping is:

<div align="center">

| Pillar | HuskyLens | Required Passing Side |
| :--- | :---: | :--- |
| 🟢 **Green** | **Color ID 1** | **Left** |
| 🔴 **Red** | **Color ID 2** | **Right** |

</div>

The most important obstacle tuning variables have been:

- camera position,
- camera viewing angle,
- driving speed,
- detection timing,
- avoidance strength,
- interaction between camera bias and PID,
- and recovery after passing a pillar.

---

# ❀ 3.6.10 Obstacle Detection Evidence ────୨ৎ────────୨ৎ────

<p align="center">
  HuskyLens detecting green pillar as Color ID 1
  &nbsp;
  HuskyLens detecting red pillar as Color ID 2
</p>

<p align="center">
  <em>
    Current HuskyLens training:
    Green = Color ID 1 and Red = Color ID 2.
  </em>
</p>

The current vision system can successfully recognize both competition pillar colors.

<div align="center">

| Pillar | HuskyLens Training | Required Passing Side |
| :--- | :---: | :---: |
| 🟢 **Green** | **Color ID 1** | **Left** |
| 🔴 **Red** | **Color ID 2** | **Right** |

</div>

Detection itself is already functional. The larger tuning challenge is converting a correct visual detection into a reliable physical maneuver.

<p align="center">
  <strong>
    Detect Pillar → React Early → Pass Correct Side → Clear Pillar → Recover → Continue
  </strong>
</p>

A correct camera classification alone does not guarantee a successful obstacle pass. Cheese must detect the pillar early enough, apply sufficient steering, clear the obstacle without carrying it, and then return to stable navigation.

This distinction became important during testing:

<p align="center">
  <strong>
    Correct Detection ≠ Successful Avoidance
  </strong>
</p>

For this reason, current obstacle tuning focuses not only on HuskyLens recognition, but also on **reaction timing, avoidance strength, pillar clearance, and post-obstacle recovery**.

---

# ❀ 3.6.11 Biggest Current Obstacle Problem: Recovery ────୨ৎ────────୨ৎ────

The most important remaining obstacle problem is what happens **after** Cheese avoids a pillar.

A successful avoidance can still become a failed run if Cheese does not recover correctly.

```text
PILLAR AVOIDED
      ↓
BAD EXIT HEADING
      ↓
ROBOT REMAINS OFFSET
      ↓
CAMERA VIEW CHANGES
      ↓
NEXT EVENT BECOMES HARDER
```

Current tuning therefore focuses heavily on:

```text
AVOID
  ↓
CLEAR
  ↓
RETURN TO PID
  ↓
RECENTER
  ↓
NEXT PILLAR
```

This is currently more important than simply making avoidance stronger.

---

# ❀ 3.6.12 Failure → Cause → Change → Result ────୨ৎ────────୨ৎ────

The following table summarizes some of the most important tuning decisions.

<div align="center">

| Failure | Cause | Change | Result / Goal |
| :--- | :--- | :--- | :--- |
| **Robot difficult to control** | Excess structure and mass | Reduced v4 mass | More predictable movement |
| **Color readings inconsistent** | Sensor height / lighting | Lowered sensor + improved logic | Better curve detection |
| **Robot zig-zagged** | Excessive correction | Minimum-correction PID | Smoother navigation |
| **Wall crashes** | PID insufficient near danger | Progressive wall protection | Fewer wall contacts |
| **Front collision risk** | Dangerous forward approach | Reverse recovery | Creates safe space |
| **Double curve count** | Repeated color event | Sequence + cooldown | One count per curve |
| **Wide curves** | Steering too weak / late | Curve tuning | Better exit position |
| **Parking inconsistency** | Finish depended on progress errors | Saved distance reference | Stop inside area |
| **Pillar detected late** | Camera angle / speed | Camera adjustment + lower speed | Earlier reaction |
| **Pillar carried** | Late / weak avoidance | Tune timing and camera bias | Clear pillar safely |
| **Next obstacle fails** | Poor recovery | Improve return to PID | Stable next approach |

</div>

This process helped the team identify the real source of each problem instead of changing unrelated values.

---

# ❀ 3.6.13 v3 → v4 Tuning Progress ────୨ৎ────────୨ৎ────

Cheese v4 was developed directly from problems observed in earlier versions.

<div align="center">

| Earlier Problem | v4 Response |
| :--- | :--- |
| Heavy structure | Reduced robot to **666 g** |
| Less favorable weight distribution | Repositioned EV3 |
| Steering needed improvement | Changed front wheel configuration |
| Color affected by lighting | Lower sensor position + improved logic |
| Wide / unstable curves | PID + curve tuning |
| Front-wall crashes | Ultrasonic reverse recovery |
| Parking inconsistency | Curve count + saved distance reference |
| Obstacle reaction problems | Camera, speed and avoidance tuning |
| Extra lighting complexity | Auxiliary lights removed |

</div>

This makes v4 an engineering response to previous testing rather than simply a visual redesign.

---

# ❀ 3.6.14 Current Results ────୨ৎ────────୨ৎ────

<div align="center">

| Area | Current Result |
| :--- | :--- |
| **Open Challenge** | 🟢 Almost final |
| **One lap** | ~30–35 s |
| **Three laps** | ~80–90 s |
| **Curve counting** | 🟢 Functional |
| **Wall avoidance** | 🟢 Functional |
| **Front recovery** | 🟢 Functional |
| **Parking** | 🟡 Works, sometimes slightly angled |
| **Obstacle detection** | 🟢 Functional |
| **Obstacle avoidance** | 🟡 Still being tuned |
| **Obstacle recovery** | 🟠 Main current challenge |
| **Obstacle parking** | 🟠 Pending |

</div>

The Open Challenge is currently the most stable part of Cheese.

The Obstacle Challenge already has functional sensing and steering influence, but avoidance and recovery still need to become more repeatable.

---

# ❀ 3.6.15 Remaining Tuning Priorities ────୨ৎ────────୨ৎ────

### Open Challenge

```text
CURVE COUNT RELIABILITY
        ↓
CURVE CONSISTENCY
        ↓
PARKING ALIGNMENT
```

### Obstacle Challenge

```text
EARLIER DETECTION
      ↓
RELIABLE AVOIDANCE
      ↓
CLEAN PILLAR CLEARANCE
      ↓
FAST RECOVERY
      ↓
NEXT PILLAR
      ↓
OBSTACLE PARKING
```

Battery condition also remains important because weaker motor response can change steering and timing during otherwise similar tests.

---

# ✦ Engineering Lessons ─── ⋆⋅☆⋅⋆ ───

### 1. Mechanics should be tuned before software

A lighter and better-balanced robot made later control adjustments easier.

### 2. Change one important variable at a time

Changing many values simultaneously makes it difficult to identify what actually improved the robot.

### 3. A successful subsystem does not guarantee a successful run

Correct color detection does not guarantee correct parking, and correct pillar detection does not guarantee successful avoidance.

### 4. Recovery matters as much as avoidance

Passing one obstacle is not enough if Cheese becomes badly positioned for the next one.

### 5. Speed must follow reliability

Performance was increased only when the robot remained controllable.

### 6. Failures are useful engineering data

Wall collisions, missed lines, wide corners, carried pillars, and bad recoveries all helped identify the next tuning priority.

---

# ✦ 3.6 Tuning Process Summary ─── ⋆⋅☆⋅⋆ ───

Cheese v4 was developed through an iterative engineering process rather than a single final design.

The tuning sequence was:

```text
MECHANICS
    ↓
COLOR SENSOR
    ↓
PID + WALL CONTROL
    ↓
CORNERS
    ↓
PARKING
    ↓
OBSTACLE DETECTION
    ↓
AVOIDANCE
    ↓
RECOVERY
```

The main development principle was:

```text
FAILURE
   ↓
UNDERSTAND WHY
   ↓
CONTROLLED CHANGE
   ↓
TEST
   ↓
MEASURE IMPROVEMENT
```

The **Open Challenge is close to final**, while the **Obstacle Challenge remains under active tuning**, especially for reliable recovery after pillar avoidance.

<p align="center">
  <strong>
    Test → Observe → Understand → Adjust → Retest → Improve
  </strong>
</p>

<p align="center">
  ✦ ─── ⋆⋅☆⋅⋆ ─── 🧀 Tuning Process Vault 🧀 ─── ⋆⋅☆⋅⋆ ─── ✦
</p>

<p align="center">
  <a href="https://github.com/Quesovamos2662/WRO2026_FE_Go-Cheese#general-project-index">
    
  </a>
</p>

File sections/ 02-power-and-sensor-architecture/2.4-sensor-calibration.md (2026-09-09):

<h1 align="center">ᯓ★ 2.4 Sensor Calibration & Reliability ᯓ★</h1>

<p align="center">
  
  
  
</p>

<p align="center">
  <em>
    Sensor calibration in Cheese is an iterative process connecting physical placement,
    real-track testing, software thresholds, and repeated driving behavior.
  </em>
</p>

<p align="center">
  ✦ ─── ⋆⋅☆⋅⋆ ─── (❁´◡`❁) ─── ⋆⋅☆⋅⋆ ─── ✦
</p>

---

A sensor being connected correctly does not automatically make its information reliable.

Its readings can change because of:

- height,
- angle,
- distance,
- lighting,
- robot speed,
- field geometry,
- mechanical alignment,
- battery condition,
- and the way the software interprets the measurement.

For this reason, Cheese v4 was calibrated primarily through **real-track testing and repeated iteration**.

<p align="center">
  <strong>
    Test → Observe → Adjust → Repeat → Compare
  </strong>
</p>

---

# ❀ 2.4.1 Calibration Strategy ────୨ৎ────────୨ৎ────

Cheese uses several sensor types, so there is no single calibration procedure that works for the entire robot.

Each sensor provides a different type of information and therefore requires a different calibration focus.

<div align="center">

| Sensor | Calibration Focus | Why |
| :--- | :--- | :--- |
| **Left Ultrasonic** | Wall distance and PID response | Controls lateral wall awareness |
| **Right Ultrasonic** | Wall distance and PID response | Controls lateral wall awareness |
| **Front Ultrasonic** | Safety and recovery distance | Detects dangerous forward proximity |
| **EV3 Color Sensor** | Real floor-marker recognition | Supports curve counting and run progress |
| **HuskyLens** | Pillar recognition and visibility | Supports obstacle avoidance |

</div>

The calibration process therefore connects:

```text
PHYSICAL PLACEMENT
        ↓
SENSOR READING
        ↓
SOFTWARE INTERPRETATION
        ↓
ROBOT RESPONSE
        ↓
REAL-TRACK RESULT
```

A problem at any stage can affect the final behavior.

This is why we do not immediately change software values every time Cheese fails.

Sometimes the actual problem is the physical position of the sensor, the robot's angle, battery condition, or another subsystem.

---

# ❀ 2.4.2 Current Calibration Status ────୨ৎ────────୨ৎ────

The current v4 system is not equally mature in every subsystem.

<div align="center">

| System | Current Status |
| :--- | :--- |
| **Color sensor** | 🟢 Functional and used during Open Challenge |
| **Left ultrasonic** | 🟢 Functional and integrated into navigation |
| **Right ultrasonic** | 🟢 Functional and integrated into navigation |
| **Front ultrasonic** | 🟢 Functional and used for safety/recovery |
| **HuskyLens** | 🟢 Trained and integrated into obstacle behavior |
| **Open sensor system** | 🟢 Mostly stable |
| **Obstacle sensing** | 🟡 Functional but still being calibrated |
| **Obstacle recovery** | 🟠 One of the main development areas |

</div>

This distinction is important.

The HuskyLens is **not merely planned** anymore.

It already detects the competition obstacle colors and influences Cheese's movement.

However:

> **Successful recognition does not automatically guarantee successful avoidance.**

The complete obstacle response also depends on approach position, visibility, speed, steering strength, wall protection, and recovery.

---

# ❀ 2.4.3 Color Sensor Calibration ────୨ৎ────────୨ৎ────

The EV3 Color Sensor faces downward toward the competition field.

<p align="center">
  Cheese v4 color sensor placement
  &nbsp;
  Cheese v4 color sensor floor gap
</p>

<p align="center">
  <em>
    Current floor-facing color-sensor position and sensor-to-track geometry.
  </em>
</p>

The color sensor is calibrated using the **real competition surface**, rather than relying only on theoretical values.

This matters because color readings can depend on several physical conditions.

<div align="center">

| Variable | Possible Effect |
| :--- | :--- |
| **Ambient lighting** | Changes reflected light |
| **Surface finish** | Changes reflection |
| **Sensor height** | Changes the amount of reflected light received |
| **Robot speed** | Changes how long the sensor remains over a marker |
| **Sensor angle** | Changes reflected-light geometry |

</div>

The current sensor position was chosen after repeated physical testing rather than by relying only on nominal specifications.

---

## ❀ 2.4.4 `COL-COLOR` Mode ────୨ৎ────────୨ৎ────

The current Open code uses the EV3 Color Sensor in:

```python
COL-COLOR
```

Instead of processing raw RGB values, the program uses the EV3 sensor's built-in color classification.

This keeps the current Open logic simpler and has proved sufficient for our track conditions.

The important software interpretation is:

```text
BLUE
  ↓
BLUE marker

RED
YELLOW ─────→ ORANGE marker
BROWN
```

Therefore:

```text
BLUE = BLUE

RED + YELLOW + BROWN = ORANGE
```

The robot does not need the EV3 sensor to perfectly classify the physical orange marker as the exact word **orange**.

It only needs to reliably determine:

> **“This reading belongs to the Orange track-marker group.”**

---

# ❀ 2.4.5 Why Orange Uses a Color Group ────୨ৎ────────୨ৎ────

During real-track testing, the orange region was not always classified by the EV3 sensor as one identical built-in color.

Depending on the conditions, the same physical marker could appear as a warm-color classification.

<div align="center">

| Physical Marker | EV3 Reading | Software Meaning |
| :--- | :--- | :--- |
| Orange | Red | ORANGE |
| Orange | Yellow | ORANGE |
| Orange | Brown | ORANGE |
| Blue | Blue | BLUE |

</div>

Instead of forcing the physical sensor to behave like a perfect digital color detector, we adapted the software to the readings actually observed during testing.

This became an important calibration principle:

> **Calibration should make the software understand the real sensor, not pretend the real sensor behaves perfectly.**

---

# ❀ 2.4.6 Color Sensor Physical Improvement ────୨ৎ────────୨ৎ────

Early testing revealed an important environmental problem:

> **Ambient light could affect floor-color detection.**

At one stage, a physical cover was tested around the color sensor to reduce external light.

However, the cover introduced a new problem.

Because it was positioned very low, it could interfere physically with the field.

The cover was therefore not retained as part of normal Cheese v4 operation.

Instead, the color sensor remained in the same general front-bottom region but was positioned **slightly lower**.

<p align="center">
  Current Cheese v4 color sensor height
</p>

<p align="center">
  <em>
    Current sensor-to-floor gap after lowering the color sensor for improved track detection.
  </em>
</p>

The development chain became:

```text
AMBIENT LIGHT AFFECTED READINGS
            ↓
PHYSICAL COVER TESTED
            ↓
COVER CREATED MECHANICAL INTERFERENCE
            ↓
SENSOR POSITION RECONSIDERED
            ↓
SENSOR LOWERED SLIGHTLY
            ↓
MORE RELIABLE FLOOR DETECTION
            ↓
COVER REMOVED
```

This became a useful example of solving a sensing problem through **mechanical calibration instead of adding more software or hardware complexity**.

---

# ❀ 2.4.7 Curve Validation ────୨ৎ────────୨ৎ────

Detecting a color does not automatically mean Cheese completed a curve.

This distinction became very important during development.

The current curve-counting system recognizes transitions between:

```text
BLUE → ORANGE
```

or:

```text
ORANGE → BLUE
```

However, the color sequence is not used alone.

Additional validation is necessary because the sensor may encounter a color even when the physical turn has not been completed correctly.

The current system therefore combines:

- color sequence,
- steering confirmation,
- timing,
- and cooldown logic.

The objective is to prevent one physical corner from being counted more than once.

---

## ❀ 2.4.8 Current Curve-Counting Calibration Values ────୨ৎ────────୨ৎ────

Current Open calibration includes:

<div align="center">

| Parameter | Current Value |
| :--- | :---: |
| **Total curve count** | **12** |
| **Color-change window** | **3.0 s** |
| **Curve cooldown** | **1.5 s** |
| **Minimum steering angle confirmation** | **0.1°** |
| **Minimum steering time** | **0.03 s** |
| **Post-color steering window** | **0.9 s** |

</div>

For the complete Open run:

```text
4 corners / lap
×
3 laps
=
12 validated curves
```

The curve counter is directly connected to the finish and parking logic.

Therefore:

```text
CORRECT COLOR DETECTION
        ↓
CORRECT CURVE VALIDATION
        ↓
CORRECT CURVE COUNT
        ↓
CORRECT RUN PROGRESS
        ↓
CORRECT PARKING ACTIVATION
```

A missed or extra curve count can make parking begin too early or too late.

---

# ❀ 2.4.9 Ultrasonic Calibration ────୨ৎ────────୨ৎ────

Cheese v4 uses **three ultrasonic sensors**.

The two lateral sensors support wall awareness and PID-based navigation.

The front sensor provides forward-distance safety information.

<p align="center">
  Cheese v4 ultrasonic sensor layout
</p>

<p align="center">
  <em>
    Current side ultrasonic layout used for lateral distance measurement.
  </em>
</p>

Ultrasonic calibration was performed mainly through repeated driving tests.

During testing we observed:

- wall distance,
- robot drift,
- correction timing,
- steering strength,
- wall contact,
- oscillation,
- and recovery behavior.

---

# ❀ 2.4.10 Why Ultrasonic Placement Matters ────୨ৎ────────୨ৎ────

Ultrasonic sensors measure distance using reflected sound.

Their physical orientation therefore matters.

If a sensor is badly aligned, its reading may not represent the wall position expected by the navigation software.

The current v4 layout places the lateral ultrasonic sensors relatively low.

<p align="center">
  Low lateral ultrasonic sensors on Cheese v4
</p>

<p align="center">
  <em>
    The low lateral layout helps keep the ultrasonic sensing direction aligned with the field walls.
  </em>
</p>

The goal is to improve the physical relationship:

```text
ULTRASONIC SENSOR
        ↓
ULTRASONIC BEAM
        ↓
FIELD WALL
```

A consistent physical orientation makes software calibration more meaningful.

---

# ❀ 2.4.11 Ultrasonic Filtering ────୨ৎ────────୨ৎ────

Raw ultrasonic measurements can fluctuate slightly.

If the steering system reacted aggressively to every individual reading, Cheese could become unstable.

The current Open controller therefore filters sensor information before it is used for navigation.

<div align="center">

| Parameter | Current Value |
| :--- | :---: |
| **Sensor filter alpha** | **0.65** |
| **Derivative filter** | **0.45** |
| **Control-loop delay** | **0.01 s** |

</div>

Filtering creates the following chain:

```text
RAW DISTANCE
     ↓
FILTERING
     ↓
MORE STABLE DISTANCE ESTIMATE
     ↓
PID ERROR
     ↓
STEERING CORRECTION
```

The objective is to suppress short measurement spikes without making the system react too slowly.

---

# ❀ 2.4.12 PID Calibration ────୨ৎ────────୨ৎ────

Sensor calibration and PID calibration are closely connected.

The ultrasonic sensors provide wall-distance information.

The PID controller determines how strongly Cheese should respond to that information.

Current Open PID values are:

<div align="center">

| Constant | Current Value |
| :--- | :---: |
| **KP** | **0.28** |
| **KI** | **0.001** |
| **KD** | **0.08** |
| **Integral limit** | **20** |
| **Center deadband** | **1.5** |
| **Maximum PID steering angle** | **32°** |

</div>

The PID controller became one of the most important parts of Open Challenge tuning.

### Too weak

```text
DISTANCE ERROR
      ↓
SMALL CORRECTION
      ↓
ROBOT CONTINUES DRIFTING
```

### Too aggressive

```text
DISTANCE ERROR
      ↓
LARGE CORRECTION
      ↓
ROBOT CROSSES TARGET
      ↓
OPPOSITE CORRECTION
      ↓
ZIG-ZAG
```

### Desired response

```text
DISTANCE ERROR
      ↓
CONTROLLED CORRECTION
      ↓
SMOOTH RETURN
      ↓
STABLE PATH
```

The goal was therefore not to obtain the strongest possible correction.

It was to obtain the **smallest useful correction that still returns Cheese to a safe trajectory**.

---

# ❀ 2.4.13 Wall-Distance Thresholds ────୨ৎ────────୨ৎ────

Not every wall distance should produce the same response.

Cheese therefore uses different protection regions.

<div align="center">

| Parameter | Current Value |
| :--- | :---: |
| **Gentle wall distance** | **28.0 cm** |
| **Severe wall distance** | **22.0 cm** |
| **Full wall-avoidance distance** | **15.0 cm** |
| **Gentle wall angle** | **14°** |
| **Severe wall angle** | **18°** |

</div>

This creates progressive correction:

```text
NORMAL DISTANCE
      ↓
PID NAVIGATION

CLOSER TO WALL
      ↓
GENTLE PROTECTION

TOO CLOSE
      ↓
SEVERE PROTECTION

VERY CLOSE
      ↓
MAXIMUM WALL-AVOIDANCE AUTHORITY
```

This is safer than waiting until Cheese is already touching the wall before applying a stronger correction.

---

# ❀ 2.4.14 Front Ultrasonic Safety Calibration ────୨ৎ────────୨ৎ────

The front ultrasonic sensor adds another protection layer.

<p align="center">
  Front ultrasonic sensor placement on Cheese v4
</p>

<p align="center">
  <em>
    Current front ultrasonic sensor placement used for forward-distance safety and recovery.
  </em>
</p>

Current front-distance parameters include:

<div align="center">

| Parameter | Current Value |
| :--- | :---: |
| **Front PID assistance begins** | **70 cm** |
| **Maximum front assist** | **10°** |
| **Too-close threshold** | **10 cm** |
| **Recovery target distance** | **30 cm** |
| **Detection confirmations** | **3** |
| **Recovery timeout** | **1.8 s** |
| **Maximum reverse steering** | **10°** |

</div>

The front ultrasonic is therefore not simply an emergency switch.

Its information can contribute before the robot reaches the most dangerous distance.

---

# ❀ 2.4.15 Front Recovery Logic ────୨ৎ────────୨ৎ────

When the front distance becomes dangerously small, Cheese can reverse to create space.

The logic can be simplified as:

```text
FRONT DISTANCE CHECKED
        ↓
       SAFE?
   ┌─────┴─────┐
  YES          NO
   │            │
CONTINUE    CONFIRM READING
                ↓
          REVERSE RECOVERY
                ↓
          INCREASE DISTANCE
                ↓
          RETURN TO NAVIGATION
```

This behavior was introduced because steering cannot always save the robot once the front of the chassis is already extremely close to the wall.

Backing away creates physical room for the steering mechanism to become useful again.

---

# ❀ 2.4.16 HuskyLens Calibration ────୨ৎ────────୨ৎ────

The HuskyLens is already trained and integrated into the current Obstacle Challenge system.

For this section, the camera evidence uses the current **camera-placement photograph** instead of the older close-up image that was not rendering correctly in GitHub.

<p align="center">
  Cheese v4 HuskyLens camera placement
</p>

<p align="center">
  <em>
    Current HuskyLens placement used for red and green obstacle recognition on Cheese v4.
  </em>
</p>

The camera is trained to recognize the two competition pillar colors.

<div align="center">

| HuskyLens ID | Obstacle | Required Passing Side |
| :---: | :--- | :--- |
| **ID 1** | 🔴 Red | Pass on the **right** |
| **ID 2** | 🟢 Green | Pass on the **left** |

</div>

The camera information reaches the EV3 through the Arduino Nano communication bridge documented in **Section 2.2 Wiring Diagram**.

Conceptually:

```text
HUSKYLENS
     ↓
I2C
     ↓
ARDUINO NANO
     ↓
USB SERIAL
     ↓
EV3
     ↓
OBSTACLE NAVIGATION
```

---

# ❀ 2.4.17 Vision Calibration Is More Than Color Recognition ────୨ৎ────────୨ৎ────

Recognizing the correct obstacle color is only the first part of camera calibration.

The camera must also detect the pillar:

- early enough,
- at a useful angle,
- while the pillar remains inside the field of view,
- and with enough time for Cheese to physically react.

This became especially important after curves.

A pillar can be correctly trained in the HuskyLens while still being missed if Cheese exits a corner with the camera pointing away from the useful region.

Therefore:

```text
GOOD COLOR TRAINING
        ≠
GUARANTEED AVOIDANCE
```

Successful obstacle behavior requires:

```text
RECOGNITION
     +
FIELD OF VIEW
     +
ROBOT POSITION
     +
DETECTION TIMING
     +
STEERING RESPONSE
     +
POST-AVOIDANCE RECOVERY
```

This is why the obstacle system must be calibrated as a complete navigation system rather than only as a camera.

---

# ❀ 2.4.18 HuskyLens Physical Calibration ────୨ৎ────────୨ৎ────

The physical angle of the camera strongly affects what Cheese can detect.

<p align="center">
  Cheese v4 HuskyLens side viewing angle
</p>

<p align="center">
  <em>
    Side view of the current HuskyLens angle used during Obstacle Challenge testing.
  </em>
</p>

Camera calibration therefore includes both **software recognition** and **physical placement**.

<div align="center">

| Variable | Why It Matters |
| :--- | :--- |
| **Camera height** | Changes the visible obstacle region |
| **Camera angle** | Changes where the field of view points |
| **Robot position** | Determines whether the pillar enters the image |
| **Distance** | Changes apparent obstacle size |
| **Speed** | Changes available reaction time |
| **Curve exit angle** | Can determine whether the next pillar is visible |

</div>

The current camera placement works, but obstacle reliability is still being tuned.

---

# ❀ 2.4.19 Arduino Nano Vision Interface ────୨ৎ────────୨ৎ────

The Arduino Nano acts as the communication bridge between the HuskyLens and EV3.

<p align="center">
  Arduino Nano position on Cheese v4
</p>

<p align="center">
  <em>
    Current Arduino Nano position used for HuskyLens-to-EV3 communication.
  </em>
</p>

The Nano receives the HuskyLens result and provides simplified obstacle information to the EV3.

The obstacle packet includes information such as:

```text
R,xCenter,width
```

for red,

```text
G,xCenter,width
```

for green,

or:

```text
N,0,0
```

when no useful obstacle is detected.

This allows the EV3 to focus on the movement decision rather than directly managing the camera protocol.

---

# ❀ 2.4.20 Current Obstacle-Sensing Behavior ────୨ৎ────────୨ৎ────

The HuskyLens currently influences Cheese's movement.

The obstacle system is therefore already beyond simple recognition testing.

Current behavior can be summarized as:

```text
HUSKYLENS SEES PILLAR
        ↓
COLOR / ID RECOGNIZED
        ↓
POSITION DATA SENT THROUGH NANO
        ↓
EV3 RECEIVES CAMERA INFORMATION
        ↓
CAMERA STEERING INFLUENCE GENERATED
        ↓
COMBINED WITH NAVIGATION / SAFETY LOGIC
        ↓
CHEESE ATTEMPTS AVOIDANCE
```

Current testing has revealed several remaining failure modes.

<div align="center">

| Failure | Current Observation |
| :--- | :--- |
| **Pillar not visible soon enough** | Avoidance can begin late |
| **Poor approach angle** | Camera may not maintain useful detection |
| **Avoidance too weak** | Cheese may contact or carry the obstacle |
| **Poor recovery** | Robot may not return to a useful path afterward |
| **Poor post-curve position** | Next pillar may enter the FOV too late |

</div>

The largest remaining challenge is not simply distinguishing red from green.

It is:

> **Recovering reliably after avoidance so Cheese is ready for the next obstacle.**

---

# ❀ 2.4.21 Speed as a Calibration Variable ────୨ৎ────────୨ৎ────

Sensor reliability is connected to robot speed.

A faster robot travels farther between sensor updates and gives the steering system less time to react.

This became especially important during obstacle testing.

Reducing speed can provide:

- more camera observation time,
- more reaction time,
- smoother avoidance,
- more useful ultrasonic corrections,
- and better recovery opportunities.

However, excessive speed reduction also increases total run time.

The trade-off is:

```text
HIGH SPEED
    ↓
FAST RUN
but
LESS REACTION TIME

LOWER SPEED
    ↓
MORE REACTION TIME
but
SLOWER RUN
```

The target is therefore:

> **The fastest speed that remains repeatable.**

---

# ❀ 2.4.22 Battery Condition as a Testing Variable ────୨ৎ────────୨ৎ────

Battery condition can also affect calibration results.

A sensor threshold may remain mathematically identical while the robot's physical response changes because the drive and steering motors do not behave exactly the same under different battery conditions.

For this reason, a failed run should not immediately be blamed on sensor calibration.

The team should consider:

```text
SENSOR?
PID?
STEERING?
MECHANICAL STRUCTURE?
BATTERY?
CAMERA VISIBILITY?
SOFTWARE TIMING?
```

This systems approach helps prevent changing a correct sensor value to compensate for a completely different problem.

---

# ❀ 2.4.23 Real-Track Calibration ────୨ৎ────────୨ৎ────

The most important calibration environment is the real field.

<p align="center">
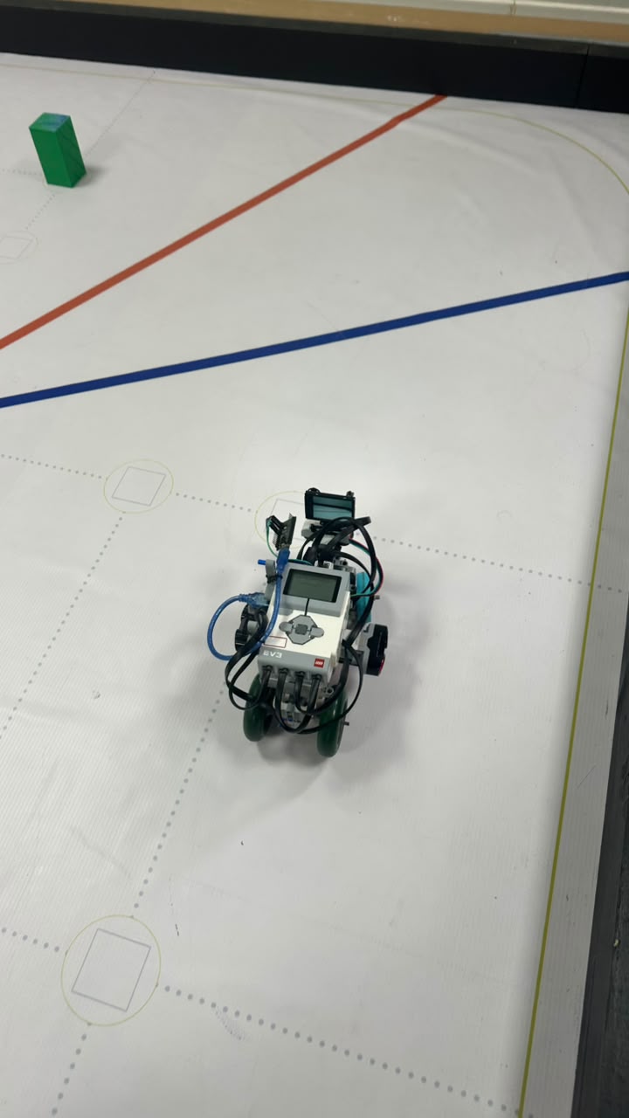
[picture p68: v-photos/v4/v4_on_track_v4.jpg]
Cheese v4 on the competition track
  
</p>

<p align="center">
  <em>
    Cheese v4 on the track where sensor placement, thresholds, PID behavior, and navigation are tested together.
  </em>
</p>

Bench testing can confirm that:

- a sensor turns on,
- a value changes,
- the camera recognizes a color,
- or communication works.

But the real track reveals whether those values are actually useful while the robot is moving.

Real-track calibration includes:

```text
LIGHTING
   +
WALL GEOMETRY
   +
ROBOT SPEED
   +
CURVES
   +
OBSTACLES
   +
MECHANICAL MOTION
   ↓
REAL SENSOR BEHAVIOR
```

---

# ❀ 2.4.24 Current Sensor Reliability Chain ────୨ৎ────────୨ৎ────

The current Cheese v4 sensing architecture can be summarized as:

```text
                     REAL ENVIRONMENT
                           │
          ┌────────────────┼────────────────┐
          │                │                │
        WALLS            FLOOR          OBSTACLES
          │                │                │
          ▼                ▼                ▼
    ULTRASONICS      COLOR SENSOR       HUSKYLENS
          │                │                │
          ▼                ▼                ▼
      FILTERING       COLOR GROUPING    NANO INTERFACE
          │                │                │
          └────────────────┼────────────────┘
                           ▼
                    SOFTWARE LOGIC
                           ▼
                STEERING + DRIVE RESPONSE
                           ▼
                      TRACK RESULT
                           ▼
                        RETUNING
```

This illustrates why calibration cannot be completely separated from software or mechanical design.

---
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

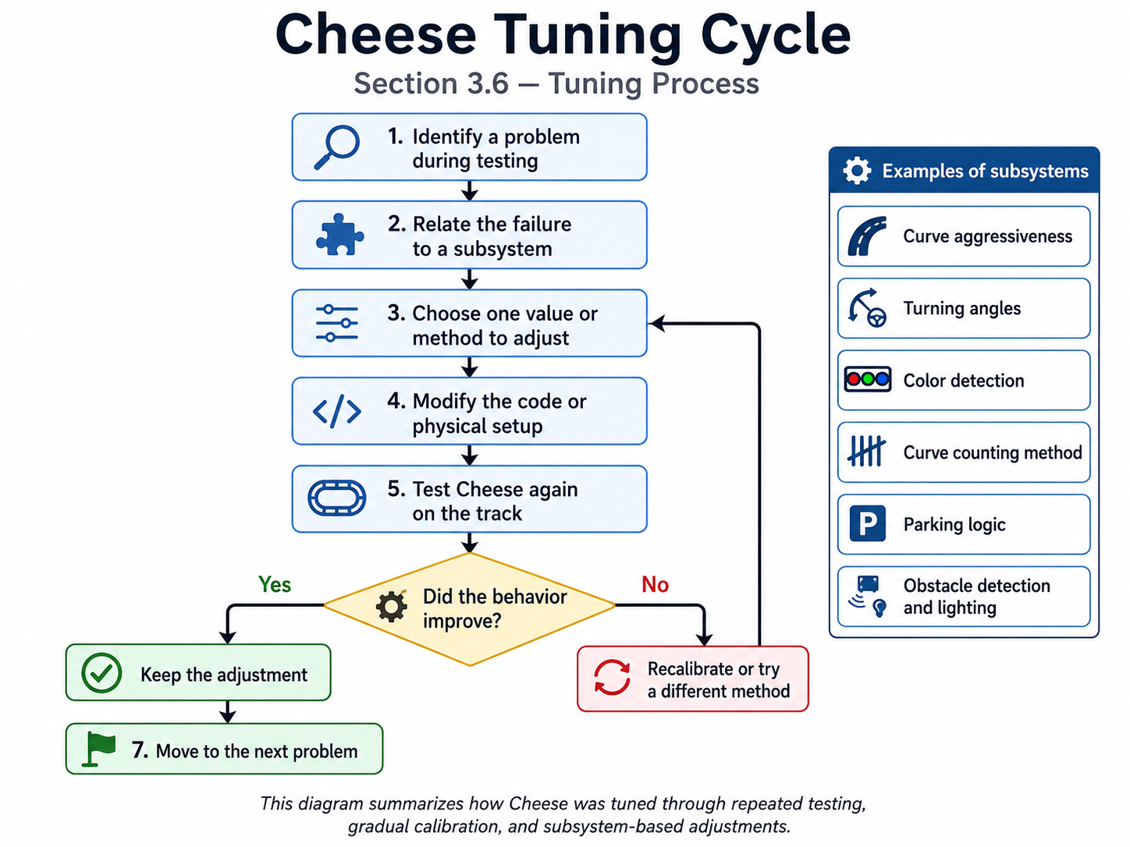
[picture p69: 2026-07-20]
img/tuning_cycle_diagram.png

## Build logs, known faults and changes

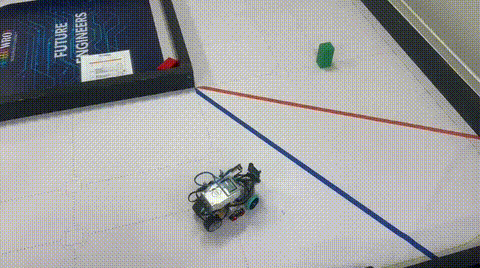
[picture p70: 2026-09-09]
v-photos/v4/open_failure_curve_collision_v4.gif

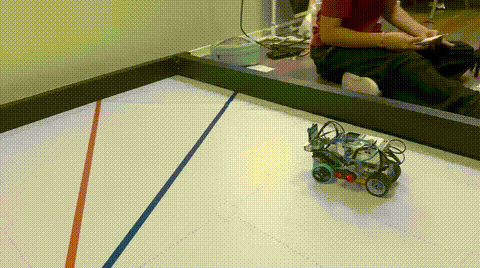
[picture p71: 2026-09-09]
v-photos/v4/open_failure_wall_collision_v4.gif

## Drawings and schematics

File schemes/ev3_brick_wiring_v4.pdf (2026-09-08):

# CHEESE v4 — EV3 PORT MAP

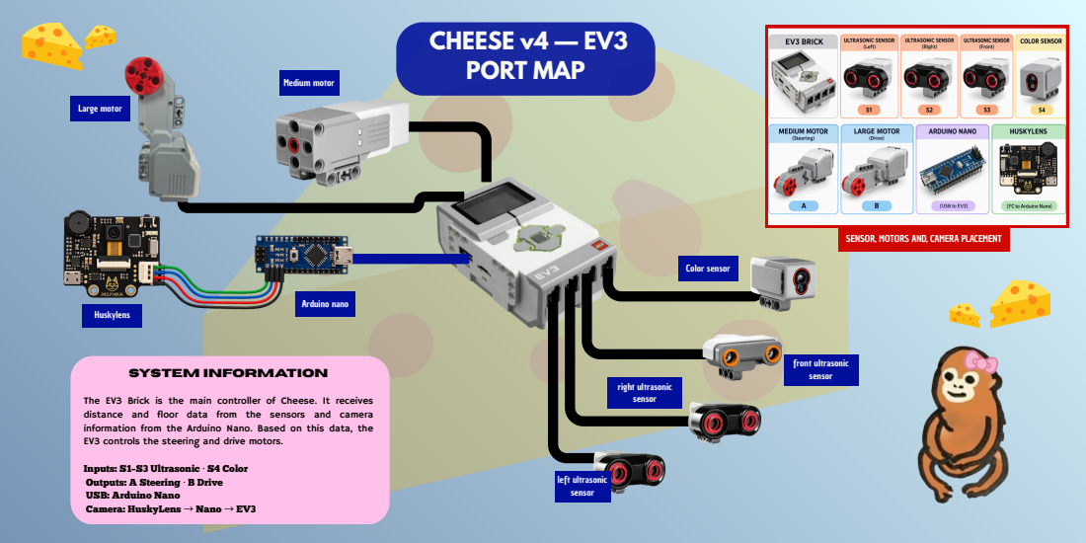
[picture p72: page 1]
left ultrasonic sensor; right ultrasonic sensor; front ultrasonic sensor; Color sensor; Medium motor; Large motor; Arduino nano; Huskylens; SYSTEM INFORMATION

SENSOR, MOTORS AND, CAMERA PLACEMENT

The EV3 Brick is the main controller of Cheese. It receives
distance and floor data from the sensors and camera
information from the Arduino Nano. Based on this data, the
EV3 controls the steering and drive motors.

Inputs: S1–S3 Ultrasonic · S4 Color
Outputs: A Steering · B Drive
USB: Arduino Nano
Camera: HuskyLens → Nano → EV3

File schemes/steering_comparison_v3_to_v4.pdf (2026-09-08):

## New steering linkage (v4) (current version)

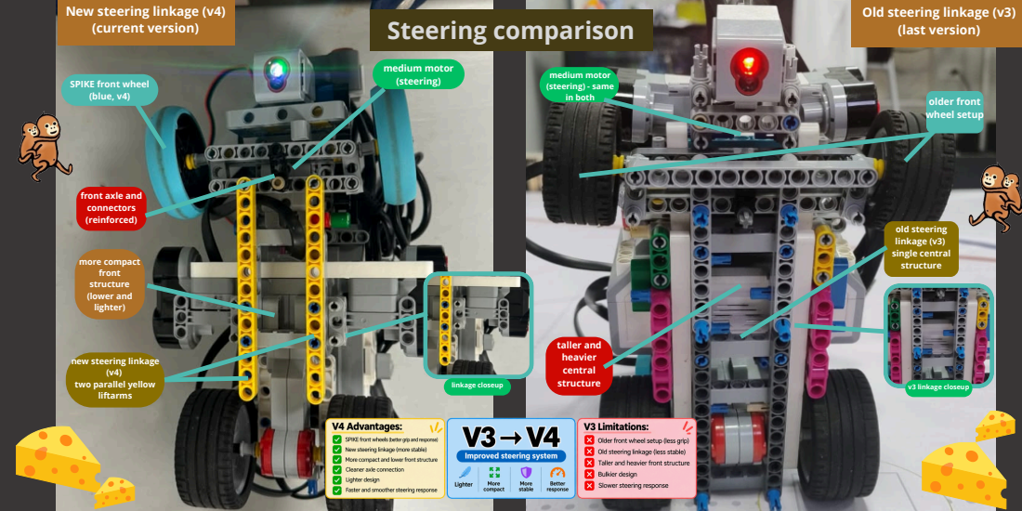
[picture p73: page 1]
(v4) two parallel yellow liftarms; medium motor; (steering); (blue, v4); more compact front structure (lower and lighter); linkage closeup; medium motor (steering) - same in both; v3 linkage closeup; older front wheel setup; old steering linkage (v3) single central structure; taller and heavier central structure; Steering comparison

Old steering linkage (v3)
(last version)

IKE front wheel

front axle and
connectors
(reinforced)

new steering linkage

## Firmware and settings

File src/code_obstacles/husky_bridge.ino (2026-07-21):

// WRO Future Engineers 2026 - Go!Cheese
// Nano side of the HuskyLens bridge. The Nano is I2C master to the
// HuskyLens (A4/A5, address 0x32) and, separately, a plain USB serial
// device to the EV3. It does not do any driving logic itself: it just
// picks the single most relevant pillar each cycle and hands the EV3 a
// small text packet it can parse in one line.
//
// Requires the "HUSKYLENS" library (DFRobot) installed in the Arduino IDE.
// Requires the HuskyLens to already be trained with Color Recognition:
// red pillar learned as ID1, green pillar learned as ID2, matching what
// was confirmed on the device screen.

#include "HUSKYLENS.h"
#include <Wire.h>

HUSKYLENS huskylens;

const int PILLAR_RED_ID = 1;
const int PILLAR_GREEN_ID = 2;

const unsigned long SERIAL_BAUD = 115200;
// Matches the EV3 main loop's ~10ms cadence (LOOP_DELAY in navigate.py) so
// the EV3 gets a fresh reading roughly every loop instead of piling up a
// serial backlog it has to catch up on.
const unsigned long SEND_INTERVAL_MS = 10;

// A real pillar is 50mm wide x 100mm tall, so its block should read
// noticeably taller than wide (~2:1 head-on). A shadow along the base of
// a wall is the opposite shape: a low, wide strip. Rejecting anything
// outside this range throws out most wall-shadow false positives before
// they're ever sent. These bounds are still an estimate, not measured --
// use DEBUG_RAW below to capture real numbers off your own hardware and
// tighten further from there.
const float PILLAR_ASPECT_MIN = 1.4;
const float PILLAR_ASPECT_MAX = 4.0;

// A shadow strip can still occasionally pass the aspect check for one or
// two frames as the camera angle sweeps through it during a curve. A real
// pillar stays in view and keeps roughly the same shape for many frames
// in a row; a shadow doesn't. This used to be the main defense against
// the wall shadow, which is why it was raised to 5 -- but the actual
// captured shadow came back at 0.52 aspect, well outside the 1.4-4.0
// window on its own, so the aspect check is doing the real rejection work
// with a wide margin. Confirm count's job now is just smoothing over
// incidental single-frame noise, not stopping the shadow, so it can run
// lower. Each frame here costs SEND_INTERVAL_MS of real reaction delay
// regardless of robot speed (2 frames = ~20ms, vs 50ms at the old value
// of 5) -- if the shadow starts getting through again, raise this back
// up before touching the aspect bounds.
const int CONFIRM_COUNT = 2;

// Set true and reflash, then run with the Nano plugged into a laptop
// (not the EV3) with the Arduino Serial Monitor open at 115200 baud.
// Point the camera at a real pillar and note the width/height/aspect it
// prints, then point it at the problem shadow near the wall and note
// those numbers too. That comparison is what should actually set
// PILLAR_ASPECT_MIN/MAX and CONFIRM_COUNT above, instead of guessing.
// Set back to false before flashing the version that runs on the EV3.
const bool DEBUG_RAW = false;

unsigned long lastSend = 0;

// Independent leaky counters per color instead of one shared streak. A
// frame that fails the aspect check costs 1 point instead of wiping the
// whole streak to 0 -- an occasional dip near the aspect boundary just
// pauses progress for a frame rather than restarting the count from
// scratch, which is what was making red (or whichever color runs closer
// to the aspect threshold on this hardware) confirm noticeably later
// than the other despite showing up on the HuskyLens screen just as fast.
// A real shadow never passes the aspect check in the first place, so it
// never earns any points here either way -- this only fixes slow
// confirmation of a real pillar, it doesn't loosen shadow rejection.
int redStreak = 0;
int greenStreak = 0;
int redWidth = 0, redXCenter = 0;
int greenWidth = 0, greenXCenter = 0;

void setup() {
  Serial.begin(SERIAL_BAUD);
  Wire.begin();

  // Keep retrying instead of giving up silently. Sending a heartbeat line
  // while waiting means the EV3 side sees "no pillar" rather than a dead
  // port if the HuskyLens is slow to power up or the cable is loose.
  while (!huskylens.begin(Wire)) {
    Serial.println(F("N,0,0"));
    delay(100);
  }

  huskylens.writeAlgorithm(ALGORITHM_COLOR_RECOGNITION);
}

void loop() {
  if (millis() - lastSend < SEND_INTERVAL_MS) {
    return;
  }
  lastSend = millis();

  int bestRedWidth = 0, bestRedXCenter = 0, bestRedHeight = 0;
  int bestGreenWidth = 0, bestGreenXCenter = 0, bestGreenHeight = 0;

  // If both pillars are visible at once (e.g. an X-intersection with
  // signs on both sides), each color's own widest block is tracked
  // separately -- whichever color actually confirms below gets used,
  // preferring the nearer one if somehow both cross the threshold on
  // the same frame. Anything that isn't a learned ID1/ID2 block, or
  // doesn't look pillar-shaped, is ignored outright.
  if (huskylens.request()) {
    while (huskylens.available()) {
      HUSKYLENSResult result = huskylens.read();
      if (result.command != COMMAND_RETURN_BLOCK) {
        continue;
      }
      if (result.ID != PILLAR_RED_ID && result.ID != PILLAR_GREEN_ID) {
        continue;
      }
      if (result.width <= 0) {
        continue;
      }
      float aspect = (float)result.height / (float)result.width;

      if (DEBUG_RAW) {
        // Extra field count (5, not 3) means the EV3's parser harmlessly
        // drops these lines if this ever accidentally ships with
        // DEBUG_RAW left on -- but flash with it off for a real run
        // regardless, this is meant for the laptop bench test only.
        Serial.print(F("DBG,"));
        Serial.print(result.ID == PILLAR_RED_ID ? 'R' : 'G');
        Serial.print(',');
        Serial.print(result.width);
        Serial.print(',');
        Serial.print(result.height);
        Serial.print(',');
        Serial.println(aspect);
      }

      if (aspect < PILLAR_ASPECT_MIN || aspect > PILLAR_ASPECT_MAX) {
        continue;
      }

      if (result.ID == PILLAR_RED_ID) {
        if (result.width > bestRedWidth) {
          bestRedWidth = result.width;
          bestRedHeight = result.height;
          bestRedXCenter = result.xCenter;
        }
      } else {
        if (result.width > bestGreenWidth) {
          bestGreenWidth = result.width;
          bestGreenHeight = result.height;
          bestGreenXCenter = result.xCenter;
        }
      }
    }
  }

  // Leaky update: a color that had a passing block this frame gains a
  // point (capped at CONFIRM_COUNT, no benefit to overshooting it); a
  // color that didn't loses a point, floored at 0 instead of snapping
  // straight back to 0 on one miss.
  if (bestRedWidth > 0) {
    redStreak = min(redStreak + 1, CONFIRM_COUNT);
    redWidth = bestRedWidth;
    redXCenter = bestRedXCenter;
  } else {
    redStreak = max(redStreak - 1, 0);
  }

  if (bestGreenWidth > 0) {
    greenStreak = min(greenStreak + 1, CONFIRM_COUNT);
    greenWidth = bestGreenWidth;
    greenXCenter = bestGreenXCenter;
  } else {
    greenStreak = max(greenStreak - 1, 0);
  }

  bool redConfirmed = redStreak >= CONFIRM_COUNT;
  bool greenConfirmed = greenStreak >= CONFIRM_COUNT;

  char confirmedColor = 'N';
  int confirmedXCenter = 0;
  int confirmedWidth = 0;

  if (redConfirmed && greenConfirmed) {
    // Both confirmed at once (an X-intersection with a sign on each
    // side) -- report whichever is currently nearer.
    if (redWidth >= greenWidth) {
      confirmedColor = 'R';
      confirmedXCenter = redXCenter;
      confirmedWidth = redWidth;
    } else {
      confirmedColor = 'G';
      confirmedXCenter = greenXCenter;
      confirmedWidth = greenWidth;
    }
  } else if (redConfirmed) {
    confirmedColor = 'R';
    confirmedXCenter = redXCenter;
    confirmedWidth = redWidth;
  } else if (greenConfirmed) {
    confirmedColor = 'G';
    confirmedXCenter = greenXCenter;
    confirmedWidth = greenWidth;
  }

  // Plain ASCII CSV, one line per reading: <color>,<xCenter>,<width>\n
  // color is 'R', 'G', or 'N' (nothing relevant, confirmed, in view).
  // xCenter and width are in HuskyLens frame pixels (320x240 frame,
  // so xCenter ranges roughly 0-320).
  Serial.print(confirmedColor);
  Serial.print(',');
  Serial.print(confirmedXCenter);
  Serial.print(',');
  Serial.println(confirmedWidth);
}

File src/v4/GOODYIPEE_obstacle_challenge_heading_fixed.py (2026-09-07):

#!/usr/bin/env python3
# ================================================================
# WRO Future Engineers 2026 - Obstacle Challenge
# Go!Cheese Team - Cheese v4
# Python 3.5.3 / ev3dev2
# ================================================================
#
# Obstacle Challenge testing version.
#
# This file is based on the current Cheese v4 navigation structure,
# but includes the HuskyLens + Arduino Nano obstacle system.
#
# The robot uses:
#   - EV3 for drive, steering, ultrasonic sensors, and color sensor.
#   - Arduino Nano as the communication bridge for the HuskyLens.
#   - HuskyLens Color Recognition for red and green pillar detection.
#
# Current obstacle rule:
#   - Red pillar   = ID 1 -> pass on the right
#   - Green pillar = ID 2 -> pass on the left
#
# The Nano sends one serial packet at a time to the EV3:
#   - R,xCenter,width  -> red pillar detected
#   - G,xCenter,width  -> green pillar detected
#   - N,0,0            -> no valid pillar detected
#
# Current status:
#   - The obstacle logic is already connected to movement.
#   - The system is still being calibrated for camera angle,
#     late detection, obstacle recovery, and obstacle parking.
#
# Main idea:
#   Normal navigation keeps the robot moving through the track.
#   When a fresh pillar detection is received, the camera adds a
#   steering bias so the robot passes the pillar on the correct side.
#   If the pillar is lost, camera steering is cleared and normal
#   steering resumes.
#
# Hardware:
#   Ultrasonic left:    INPUT_1
#   Ultrasonic right:   INPUT_2
#   Ultrasonic front:   INPUT_3
#   Color sensor:       INPUT_4
#   Medium steering:    OUTPUT_A
#   Large drive motor:  OUTPUT_B
#   Arduino Nano:       EV3 USB port
#   HuskyLens:          Connected to Arduino Nano
#
# ================================================================

from ev3dev2.motor import (
    LargeMotor,
    MediumMotor,
    OUTPUT_A,
    OUTPUT_B,
    SpeedPercent
)
from ev3dev2.sensor import INPUT_1, INPUT_2, INPUT_3, INPUT_4
from ev3dev2.sensor.lego import UltrasonicSensor, ColorSensor
from ev3dev2.button import Button
from ev3dev2.display import Display
from ev3dev2.sound import Sound
from time import sleep, time
import threading
import serial


# ================================================================
# HARDWARE
# ================================================================
steering = MediumMotor(OUTPUT_A)
drive = LargeMotor(OUTPUT_B)

left_sensor = UltrasonicSensor(INPUT_1)
right_sensor = UltrasonicSensor(INPUT_2)
front_sensor = UltrasonicSensor(INPUT_3)
color_sensor = ColorSensor(INPUT_4)

buttons = Button()
screen = Display()
sound = Sound()

left_sensor.mode = 'US-DIST-CM'
right_sensor.mode = 'US-DIST-CM'
front_sensor.mode = 'US-DIST-CM'
color_sensor.mode = 'COL-COLOR'

steering.reset()
sleep(0.5)


# ================================================================
# MOVEMENT SETTINGS
# ================================================================
# Negative speed is forward for this robot.
NORMAL_SPEED = -38
GENTLE_WALL_SPEED = -32
SEVERE_WALL_SPEED = -28

# Positive speed is backward.
EMERGENCY_REVERSE_SPEED = 28

# The motor moves quickly, but requested angles still ramp smoothly.
STEERING_SPEED = 70
STEERING_DEADBAND = 0.4
STEERING_TURN_STEP = 4.65
STEERING_RETURN_STEP = 8.0
STEER_DIRECTION = 1
# Use this only to correct a small mechanical centering offset. For example,
# if zero points 2 degrees left, try +2.0 or -2.0 and verify at low speed.
STEERING_CENTER_OFFSET = 0.0

MAX_PID_ANGLE = 30.0

# KEEP THESE DISTANCES THE SAME.
WALL_GENTLE_DISTANCE = 20.0
WALL_SEVERE_DISTANCE = 18.0

KP = 0.62
KI = 0.0
KD = 0.14

INTEGRAL_LIMIT = 0.0

# Filters remove tiny ultrasonic jumps and derivative spikes.
# Higher SENSOR_FILTER_ALPHA = faster response to new sensor readings.
SENSOR_FILTER_ALPHA = 0.75
DERIVATIVE_FILTER_ALPHA = 0.40

# A diagonal sensor can see past a corner and report a very large distance.
# Limit only the values used by steering; safety still uses raw readings.
MAX_CONTROL_DISTANCE_CM = 110.0
MAX_CONTROL_STEP_CM = 18.0

LOOP_DELAY = 0.01


# ================================================================
# HUSKYLENS PILLAR AVOIDANCE (Nano over USB serial)
# ================================================================
# The Nano sends one line at a time as: R,xCenter,width / G,xCenter,width /
# N,0,0. HuskyLens Color Recognition must be trained as ID1=RED, ID2=GREEN.
HUSKY_PORT = '/dev/ttyUSB0'
HUSKY_BAUD = 115200

# Ignore distant/noisy blocks below this width. Width is still used to slow the
# robot and to reject tiny detections, but steering is now driven mainly by the
# pillar's horizontal image position, as in ShahroodRC's controller.
PILLAR_MIN_WIDTH = 6
PILLAR_FULL_WIDTH = 30
PILLAR_INITIAL_RAMP = 0.60
PILLAR_BIAS_ANGLE = 30.0
PILLAR_BIAS_SMOOTHING = 0.70
PILLAR_STALE_S = 0.15
PILLAR_APPROACH_SPEED = -18

# HuskyLens uses an approximately 0..320 horizontal coordinate. Instead of a
# fixed color angle, make each pillar move toward a color-specific image point:
# RED at the left of the image -> robot passes on its right.
# GREEN at the right of the image -> robot passes on its left.
CAMERA_CENTER_X = 160.0
PILLAR_TARGET_X = {'RED': 70.0, 'GREEN': 250.0}
PILLAR_X_GAIN = 0.55
PILLAR_MIN_DIRECTION_ANGLE = 12.0

# Cheese's physical steering motor uses the opposite sign from the logical
# camera convention: negative motor angle turns right, positive turns left.
# Apply this only to pillar steering so curve and wall steering stay unchanged.
PILLAR_STEERING_SIGN = -1.0

# Camera movement toward a wall fades out as that wall approaches the existing
# 24 cm correction threshold. It is unrestricted at/above 40 cm.
PILLAR_WALL_SAFE_CM = 24.0
PILLAR_WALL_FREE_CM = 40.0


# ================================================================
# MINIMUM-CORRECTION PID STEERING
# ================================================================
# The robot normally commands zero steering. PID activates only for a confirmed
# curve or when a side wall is extremely close.
CURVE_FRONT_TRIGGER_CM = 70.0
CURVE_OPEN_SIDE_MIN_CM = 32.0
CURVE_OPENING_DIFFERENCE_CM = 9.0
CURVE_ERROR_GAIN = 0.85
CURVE_ERROR_MIN = 22.0
CURVE_ERROR_MAX = 46.0

# Start early enough that a small correction can prevent an emergency. Above
# 24 cm the robot still drives straight without continuous centering.
CORRECTION_WALL_DISTANCE_CM = 24.0
WALL_ERROR_GAIN = 1.8
WALL_ERROR_MIN = 8.0
WALL_ERROR_MAX = 24.0

CORRECTION_SPEED = -35
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

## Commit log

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2026-06-17 Added more details about the motors
    Expanded the information significantly regarding the large and medium motors.
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2026-06-18 Enhance README with PID controller details and future plans
    Expanded explanation of PID controller implementation and its advantages over manual adjustments. Discussed the rare occurrences of erroneous inputs and future plans for camera integration.
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2026-06-18 Correct sensor type and add assembly instructions link
    Updated sensor descriptions and added a link to assembly instructions.
2026-07-06 Enhance README with driving base and liftarm details
    Added sections on driving base, chassis, and technical liftarms with benefits.
2026-07-06 Enhance benefits section for technical liftarms
    Clarified benefits of using liftarms, including their lightweight nature, rigidity, and specific hole placements for precise positioning.
2026-07-06 Enhance README with benefits of axles and pins
    Added benefits section to highlight the importance of axles and pins in the build.
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2026-07-06 Expand README with liftarms and pins/axles analysis
    Added analysis of liftarms and pins/axles, including benefits, disadvantages, and conclusions on their impact on chassis performance.
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2026-07-10 Enhance README with project details and team goals
    Expanded on the project's decision-making system and PID controller details, including tuning goals and team objectives for the National Finals.
2026-07-10 Revise README with updated dimensions and chassis info
    Updated dimension constraints and chassis weight details. Enhanced descriptions of sensing capabilities and chassis stability improvements.
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2026-07-13 Document testing results for drivetrain components
    Added testing results for rear tires and motors, highlighting performance under various conditions.
2026-07-13 Document software control of steering in 1.3.5
    Added a new subsection on software control of the steering, detailing how code commands the steering angles and motor position.
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2026-07-15 Enhance priority chain in logic overview
    Added additional layers to the priority chain for better control.
2026-07-15 Change color sensor mode and update library imports
    Updated color sensor mode to COL-COLOR for built-in classification and modified library imports for clarity.
2026-07-15 Document steering priority chain and decision logic
    This section explains the steering priority chain for the robot, detailing the decision-making process and the functions involved in steering behavior. It outlines the layers of decision-making, incl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
2026-07-16 Delete Mobility & Mechanical Design section from README
    Removed detailed section on Mobility & Mechanical Design, including chassis, liftarms, motors, and steering mechanism.
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2026-07-16 Add flowchart image to README
    Added a flowchart image to illustrate the robot's logic.
2026-07-16 Include note on AI support for flowchart logic
    Added a note about the flowchart's creation using AI.
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2026-07-16 Document PID Controller functionality and design
    Added detailed explanation of the PID controller, its functionality, and its components, including error calculation and correction mechanisms.
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2026-07-16 broken pin
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2026-07-17 Enhance design decision log with visuals and details
    Added visual references and images to enhance the design decision log, illustrating the layout and sensor placement of Cheese v3. Included details about mechanical issues encountered during testing and corresponding design responses.
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2026-07-17 Revise torque and speed calculations for clarity
    Updated the torque and speed calculations section to clarify the relationship between motor selection, tire size, and robot behavior. Improved explanations of drivetrain performance, speed layers, an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
2026-07-17 Revise design decision log for clarity and detail
    Updated the design decision log to clarify engineering decisions made for Cheese v3. Enhanced explanations of design principles, decision impacts, and the rationale behind sensor and control choices.
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2026-07-21 3D model concept
    [cheese_v3_concept_model.obj]
2026-07-21 v3 3D model
    [cheese_v3_concept_model.stl]
2026-07-21 chassis model
    [chassis_concept_model.stl]
2026-08-26 Revise robot mass and motor function details
    Updated robot mass specifications and clarified motor functions for v3 and v4. Improved structure and cable routing details.
2026-08-27 Enhance structural component documentation with new sections
    Added sections on physical evidence of pins, axles, and structural simplification from v3 to v4, including images and explanations of design choices.
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2026-08-28 Revise project overview for Cheese v4 updates
    Updated project overview to reflect changes in Cheese v4, including design improvements, sensor placement, and documentation focus.
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2026-08-31 Refactor sensor placement section and update title
    Removed the Sensor Placement Checklist section and updated the following section title from 'Sensor Placement Checklist' to 'Sensor Testing and Lessons'.
2026-09-02 Revise design decision log for Cheese v4 clarity
    Updated the design decision log for Cheese v4 to clarify engineering decisions, simplify language, and enhance readability. Key changes include a focus on weight reduction, sensor placement, and over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
2026-09-02 Revise Bill of Materials for Cheese v4
    Updated the Bill of Materials to reflect changes from Cheese v3 to v4, including component modifications, removals, and new additions. Enhanced clarity on the purpose and functionality of each compon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
2026-09-04 minimum correction pid controller
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2026-09-07 Revise obstacle challenge strategy and documentation
    Updated the obstacle challenge documentation to reflect changes in robot strategy, including improved camera detection, obstacle avoidance behavior, and system architecture.
2026-09-07 Revise corner handling documentation for clarity
    Updated the corner handling section to improve clarity on the robot's corner detection and response logic, including the introduction of new subsections and enhanced explanations of the color sensor'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
2026-09-09 Remove outdated images and update drivetrain description
    Removed images and descriptions related to the EV3 Medium Motor and previous installations. Updated the text to focus on the v4 redesign of the drivetrain layout.
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2026-09-09 Fix missing newline at end of wiring diagram file
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2026-09-09 Fix image link for HuskyLens camera mounting
    Updated image source for HuskyLens mounting close-up.
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2026-09-09 Revise sensor calibration documentation for clarity
    Updated sensor calibration documentation with improved clarity and detail on calibration strategies, current sensor statuses, and the importance of real-track testing. Adjusted formatting and corrected minor inaccuracies throughout the document.
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2026-09-09 Revise corner handling documentation for clarity
    Updated corner handling documentation to improve clarity on the corner handling process, including objectives, current status, and testing plans. Enhanced descriptions of the robot's behavior during corner navigation and obstacle avoidance.
